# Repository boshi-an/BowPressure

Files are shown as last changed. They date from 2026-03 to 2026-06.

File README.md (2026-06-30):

# Force-sensing Violin/Cello Bow Setup

This repo provides a systemetical way to capture human violin playing data.

## Preparation (From Scratch)

- Arduino Uno (R3 or R4)
- High Precision AD HAT [Weshare](https://www.waveshare.com/wiki/High-Precision_AD_HAT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)
- BNO055 board [DFRobot](https://wiki.dfrobot.com/sen0374/)
- Bow attached with strain gauges

## Wirings (From Scratch)

Before powering the board, please check twice the connections to avoid burning the board!!!

Arduino UNO -> AD HAT:

- Arduino `D13 (SCK)` -> `SCLK`
- Arduino `D11 (MOSI)` -> `DIN`
- Arduino `D12 (MISO)` -> `DOUT`
- Arduino `D10` -> `CS`
- Arduino `D2` -> `DRDY`
- Arduino `D4` -> `RESET` / `REST`
- Arduino `5V` -> `VCC` (digital logic supply)
- Arduino `5V` -> `AVDD` (analog supply) via the screw terminal block

For the differential mode used in this project, the following shoud NOT be connected:
- `GND` -> `AVSS`

AD Hat to Bow Bridge

- AD Hat `IN0-VCC` -> Bow `E+`
- AD Hat `IN0-GND` -> Bow `E-`
- AD Hat `IN0-AIN` -> Bow `S+`
- AD Hat `IN1-AIN` -> Bow `S-`

Arduino UNO -> BNO055

- Arduino `SDA` -> `SDA`
- Arduino `SCL` -> `SCL`
- Arduino `5V` -> `VCC`
- Arduino `GND` -> `GND`

Arduino UNO -> LTC signal

- Arduino `D3` -> Normalized input

The Normalized input is the raw input biased to fit the Arduino logic.

## Wirings (Already integrated)

- Label ADC:L and ADC:R to ADC. Read the section above to understand the connector orientation.
- Label AVDD to the AVDD screw terminal on the ADC board.
- Label ARD:1, ARD:2 and ARD:3 to Arduino. Read the section above to understand the connector orientation.

## Compiling

Before powering the board, please check twice the connections to avoid burning the board!!!

1. Connect the Arduino to computer
2. Connect the Arduino to 9-12V power input
3. List boards connected 

```bash
arduino-cli board list
```

4. Compile controller program (pick the right FQBN for your board, as displayed by the previous command)

```bash
arduino-cli compile --fqbn <FQBN> realtime-arduino/ads1263_bno055_reader
```

5. Upload program to controller

```bash
arduino-cli upload -p <PORT> --fqbn <FQBN> realtime-arduino/ads1263_bno055_reader
```

6. Monitor output

For graphical monitoring:

```bash
python realtime-arduino/graphics_logger.py
```

This script supports loading fitted acceleration compensation model and display the compensated readings in realtime.

For legacy command-line based monitoring and recording:

```bash
python realtime-arduino/stream_logger.py --port <PORT> --baud 230400 --output recordings/ads1263.csv
```

## Calibration

Calibration requires the Arduino already running the controller above.

```bash
python realtime-arduino/calibration.py calibrations/bow.json
```

The calibration data will be appended to the old file if exists.

## Calibration Fitting

```bash
python analysis_calibration_data.py calibrations/bow.json
```

This will generate the quadratic terms for the calibration in `calibrations/bow_params.json`

## Acceleration Compensation

Acceleration Compensation requires a recorded csv file generated by `realtime-arduino/stream_logger.py`

```bash
python acceleration_compensation/fit.py recordings/ads1263.csv --model <mlp/linear> --epochs 1000 --n-past 10 --n-future 0
```

The program will save the fitted model to the same directory of the csv file.

## LTC Input

LTC input requires an additional LM2903P chip for pulling the input voltage to Arduino logic. The [ltc_reader](realtime-arduino/ads1263_bno055_reader/ads1263_bno055_reader.ino) includes a sample code for displaying received LTC timestamps, the [main_program](realtime-arduino/ads1263_bno055_reader/ads1263_bno055_reader.ino) supports LTC input, when LTC input is available, timestamps will automatically be included in the saved trace files. Files need modifications on `LTC_FPS` to adapt to your specific LTC setting.

The schematics for LTC reading circuit are included [in this file](figures/Circuit/SCH_Schematic2_2026-04-30.pdf). The circuit is capable of detecting very small signals (less than 100mVpp) to large signals (up to 3.3Vpp). The signal is not required to be centered at 0V.

You may generate LTC signals by playing LTC audio generated [on this website](https://elteesee.pehrhovey.net) and wire it to the LTC input circuit through the 3.5mm Audio Jack.

The compatibility with [Cubase LTC](https://www.steinberg.help/r/cubase-pro/15.0/en/cubase_nuendo/topics/synchronization/synchronization_timecode_standards_c.html) still requires confirmation, but in theory it should work.

# Data Collection with Mocap

The sensorized bow can be used together with april tag clamps on the bow and the violin to do violin playing motion data captuer.

The 3D model files for the clamps are at [OnShape](https://cad.onshape.com/documents/7d9b660bd9e12f1896edefd1/w/8b9ee4686a368937af61d3e0/e/939a0500c785a22a848d996b). These models are also licensed under [CC BY-NC-SA 4.0](https://creativecommons.org/licenses/by-nc-sa/4.0/).

The apriltags models are at [here](figures/Apriltags).

The Mocap data processing pipeline is not yet opensourced.

## Data Compression

To capture human motion and instrument pose at the same time, we used visible light motion capturing system (different from usual IR based mocap system).

The raw data of motion capture is trmendously big. At [ETH AIT volumetric capturing lab](https://volumetric-capture.ait.ethz.ch/), the produced data is aronud 200GB per second.

For more efficient data transmission, storage and processing, we developed ways to compress the raw data into more compact forms. We have provided a script for compressing `.dng` raw images of motion capture frames into mp4 videos or jpg images. With mp4 compression, we can have a compression rate of over `2000x`.

This script works with any generic directory structure. It replaces dng files with mp4 videos or jpg files in the destination path, and copies any other files as-is.

This command will compress the dataset into mp4 files:

```bash
python compress_dataset.py --src SRC_PATH --dst DST_PATH --skip-preview --crf 30 --workers 4 --resume
```

The `--crf` option controls the quality, the lower the better quality and larger size. 30 keeps the details of the images and still have a very small file volume. Notice that MP4 encoding uses motion compensation, which uses predicted pixel block movement to encode motion thus harmful for accuracy of motion capture. So if you want unbiased data, we recommend you use the following jpg style compression, which preserves the motion but loses pixel color fidelity.

This command will compress the dataset into jpg files:

```bash
python compress_dataset.py --src /mnt/ait/work/srl_lab/cameras/SRL_lab/violin_test_Jun16 --dst /mnt/violin/Violin_test_Jun16 --skip-preview --format jpg --jpeg-quality 85 --workers 4
```

Teh `--jpeg-quality` controls the quality, the higher the better quality. 85 is a very high quality, usually we can lower this to 65 or even smaller numbers.

# License

This project is licensed under [CC BY-NC-SA 4.0](https://creativecommons.org/licenses/by-nc-sa/4.0/).  
Free for research and personal use. Commercial use is prohibited.  
Derivatives must use the same license.

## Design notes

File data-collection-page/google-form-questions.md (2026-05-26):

# Google Form — Violin Playing Study

**Form title:** Violin Playing Study — Sign-up & Background Form
**Subtitle:** Force-sensitive Violin Playing Dataset · ETH Zurich Soft Robotics Lab

**Form description:**
> Thank you for your interest in participating in our violin playing research study at ETH Zurich. This form takes about 5 minutes. We will use your answers to confirm eligibility and schedule your session.
>
> Contact: Boshi An · boshan@ethz.ch · Soft Robotics Lab, ETH Zurich

---

## Section 1 — Contact & Scheduling

1. **Full name** *(short answer, required)*
2. **Email address** *(short answer, required)*
3. **Phone number** *(short answer, optional)*
4. **Preferred session dates / availability** *(paragraph, e.g. "weekday afternoons after May 15")*

---

## Section 2 — Eligibility Screening

5. **Are you 18 years of age or older?** *(required)*
   - Yes
   - No → *route to not-eligible closing screen*

6. **Do you currently have any musculoskeletal pain or injury that would make violin playing uncomfortable or unsafe?** *(required)*
   - No
   - Yes — please describe below

   6a. If yes, please describe briefly *(short answer, shown only if Yes)*

7. **Do you have photosensitive epilepsy or a related condition?** *(required)*
   - No
   - Yes → *route to not-eligible closing screen*

> ⚠️ The study uses bright infrared strobe lights for motion capture. Participants with photosensitive epilepsy or a related condition are not eligible.

---

## Section 3 — Musical Background

8. **How many years have you been playing violin?** *(required)*
   - 5–9 years
   - 10–14 years
   - 15–19 years
   - 20+ years

9. **How would you describe your current playing level?** *(required)*
   - Advanced (conservatory / university level)
   - Professional / semi-professional

10. **Bowing hand** *(required)*
    - Right hand
    - Left hand

11. **What is your primary musical context?** *(checkboxes, select all that apply)*
    - Classical / orchestral
    - Chamber music
    - Folk / traditional
    - Jazz / improvised
    - Other

12. **Do you have any upcoming performance or competition in the next 4 weeks that might be affected by participating?**
    - No
    - Yes

---

## Section 4 — Piece Preparation

> The lab provides a violin and bow — you do not need to bring your own instrument.

13. **What piece(s) are you planning to prepare for the session?** *(paragraph, required)*
    - Title, composer, approximate duration (e.g. "Bach Partita No. 2 in D minor, ~12 min")

14. **Estimated total performance duration** *(required)*
    - 3–5 min
    - 5–10 min
    - 10–15 min

---

## Section 5 — Data Consent Preferences

> A full printed consent form with your signature will be completed at the start of your session. These questions capture your initial preferences — you can change them on the day.

15. **I agree that my data (motion, force, audio) may be published in anonymised form in scientific outputs.** *(required)*
    - Yes, I agree
    - I have questions — please contact me

16. **I would like my data published or shared in non-anonymised form (linked to my identity).**
    - Yes
    - No, keep my data anonymised only

17. **I would like my data shared with academic collaborators outside ETH Zurich in non-anonymised form.**

    > Sharing with collaborators means your data (motion, force, audio) may be accessed by a small number of researchers in selected partner groups (e.g. Tsinghua University) for the purposes of this study. This is closed-circulation academic sharing — it does not mean your data will be published publicly or non-anonymously. Sharing with collaborators allows for broader scientific analysis and benefits the research community. You can still choose to have all public outputs anonymised regardless of your answer here.

    - Yes, I agree to share my data with selected academic collaborators in non-anonymised form
    - No, limit access to the ETH Zurich research team only

18. **I would like to be notified about the study results.**
    - Yes
    - No

---

## Section 6 — Anything Else?

19. **Any questions or comments for the researcher?** *(paragraph, optional)*

---

## Setup Notes

- **Routing:** use "Go to section based on answer" on Q5 (No) and Q7 (Yes) to send ineligible respondents to a closing screen.
- **Confirmation message:** *"Thank you! Boshi will contact you within a few days to schedule your session."*
- **Response notifications:** enable email alerts to boshan@ethz.ch on each submission.
- The printed consent form with physical signatures must still be completed in person — this form does not replace it for ETH ethics compliance.

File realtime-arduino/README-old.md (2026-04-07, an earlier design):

## Arduino ADS1263 Examples

Arduino sketches for the Waveshare High-Precision AD HAT (ADS1263), tested with **Arduino UNO** and **Arduino Mega 2560**.

### Sketches

- `arduino_self_check/arduino_self_check.ino`
  - Basic board health check (serial output, LED heartbeat, optional A0 read).
- `ads1263_reader/ads1263_reader.ino`
  - ADS1263 differential capture on `IN0-IN1`
  - DRDY falling-edge interrupt sampling
  - Continuous streaming output lines: `DATA,timestamp_us,raw,mV`
  - Periodic stream stats lines: `STATS,fps=...,count=...,dropped_edges=...`
- `bno055_reader/bno055_reader.ino`
  - BNO055 IMU over I2C (`SDA`/`SCL`), **no third-party IMU library** (raw register I²C)
  - **ACCGYRO** mode only; configurable accel G-range, gyro °/s range, and both sensors’ bandwidth (see `bno055_reader/BNO055_ACC_GYRO.md`)
  - Outputs CSV: `t_ms,acc_x,acc_y,acc_z,gyr_x,gyr_y,gyr_z` (units: mg, dps)
- `ltc_reader/ltc_reader.ino`
  - Reads LTC (Linear Timecode) on `D2` (UNO `INT0`, edge interrupt)
  - Prints current decoded SMPTE timecode lines: `HH:MM:SS:FF`
- `stream_logger.py`
  - Laptop-side logger that waits on serial stream and records CSV

### Wiring (UNO -> AD HAT)

- `D13 (SCK)` -> `SCLK`
- `D11 (MOSI)` -> `DIN`
- `D12 (MISO)` -> `DOUT`
- `D10` -> `CS`
- `D2` -> `DRDY`
- `D4` -> `RESET` / `REST`
- `5V` -> `AVDD` (analog supply)
- `5V` -> `VCC` (digital logic supply)
- `GND` -> `AVSS` (or `COM` if AVSS-COM is already tied)

### Wiring (Mega 2560 -> AD HAT)

- `D52 (SCK)` -> `SCLK`
- `D51 (MOSI)` -> `DIN`
- `D50 (MISO)` -> `DOUT`
- `D53` -> `CS`
- `D2` -> `DRDY`
- `D4` -> `RESET` / `REST`
- `5V` -> `AVDD` (analog supply)
- `3.3V` -> `VCC` (digital logic supply)
- `GND` -> `AVSS` (or `COM` if AVSS-COM is already tied)

### Important Electrical Note

The AD HAT is Raspberry-Pi-oriented (3.3V logic). UNO/Mega pins are 5V.
Use level shifting on outputs (`SCLK`, `DIN`, `CS`, `RESET`) for safe operation.

### Build and Upload (arduino-cli)

From project root:

```bash
cd /home/boshi/Documents/BowPressure
```

List boards/ports:

```bash
arduino-cli board list
```

Compile ADS1263 reader (pick the right FQBN for your board):

```bash
arduino-cli compile --fqbn <FQBN> realtime-arduino/ads1263_reader
```

Compile self-check (pick the right FQBN for your board):

```bash
arduino-cli compile --fqbn <FQBN> realtime-arduino/arduino_self_check
```

Compile LTC reader:

```bash
arduino-cli compile --fqbn <FQBN> realtime-arduino/ltc_reader
```

Upload ADS1263 reader:

```bash
arduino-cli upload -p /dev/ttyACM1 --fqbn <FQBN> realtime-arduino/ads1263_reader
```

Important: the `--fqbn` must match the exact board you are using.
For example:
- Arduino UNO R4 WiFi: `arduino:renesas_uno:unor4wifi`
- Arduino UNO (classic AVR): `arduino:avr:uno`
- Arduino Mega 2560 (AVR): `arduino:avr:mega`
- Do `arduino-cli board list` to see your fqbn.

Replace `/dev/ttyACM1` with the port shown by `arduino-cli board list` for your setup.

### Laptop Logger

Install dependency:

```bash
python -m pip install pyserial
```

Run logger (matches sketch baud rate `230400`):

```bash
python realtime-arduino/stream_logger.py --port /dev/ttyACM1 --baud 230400 --output ads1263_stream.csv
```

Optional timed run (example: 20 seconds):

```bash
python realtime-arduino/stream_logger.py --port /dev/ttyACM1 --baud 230400 --output ads1263_stream.csv --duration 20
```

### Expected ADS1263 Reader Output

- Register configuration verification lines (`REG_MODE*`, `REG_REFMUX`)
- Stream start message
- Repeating sample lines:
  - `DATA,timestamp_us,raw,mV`
- Periodic status lines:
  - `STATS,fps=...,count=...,dropped_edges=...`

### BNO055 (IMU) Wiring + Notes

- Connect IMU `SDA` -> Arduino `SDA` (UNO R4: labeled SDA, often D14)
- Connect IMU `SCL` -> Arduino `SCL` (UNO R4: labeled SCL, often D15)
- Connect IMU `3V3` (or `VIN` per breakout) and `GND` per your board datasheet
- Default I2C address is usually `0x28` (`BNO055_ADDRESS_A`); some boards use `0x29`

**UNO R4 WiFi** — compile/upload example (adapt port from `arduino-cli board list`):

```bash
arduino-cli compile --fqbn arduino:renesas_uno:unor4wifi realtime-arduino/bno055_reader
arduino-cli upload -p /dev/ttyACM0 --fqbn arduino:renesas_uno:unor4wifi realtime-arduino/bno055_reader
arduino-cli monitor -p /dev/ttyACM0 -c baudrate=115200
```

No extra libraries are required for `bno055_reader` (uses `Wire` only).

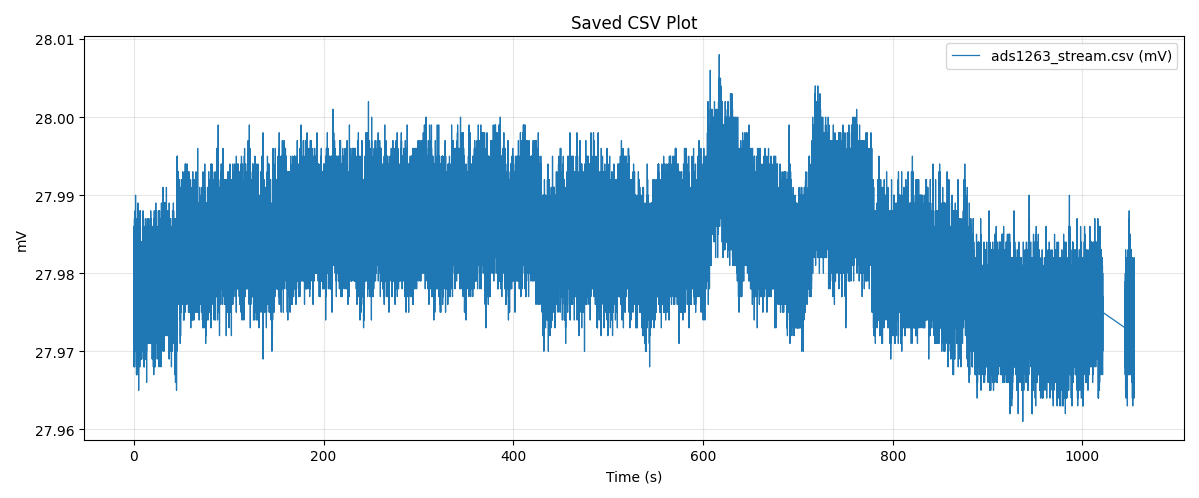
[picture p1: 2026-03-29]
figures/drift-CA80-full-5h.png

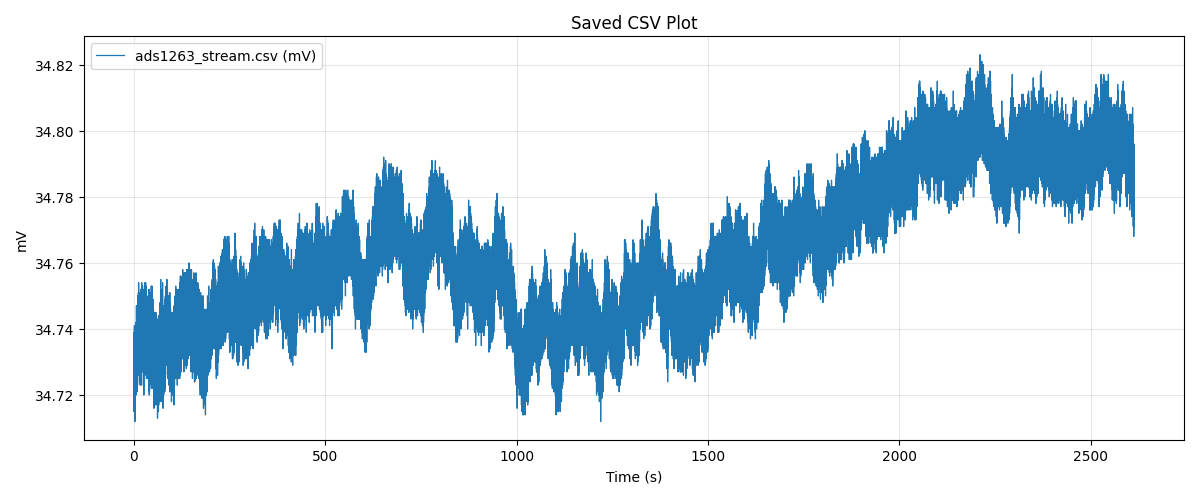
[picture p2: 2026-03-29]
figures/drift-406-half-10d.png

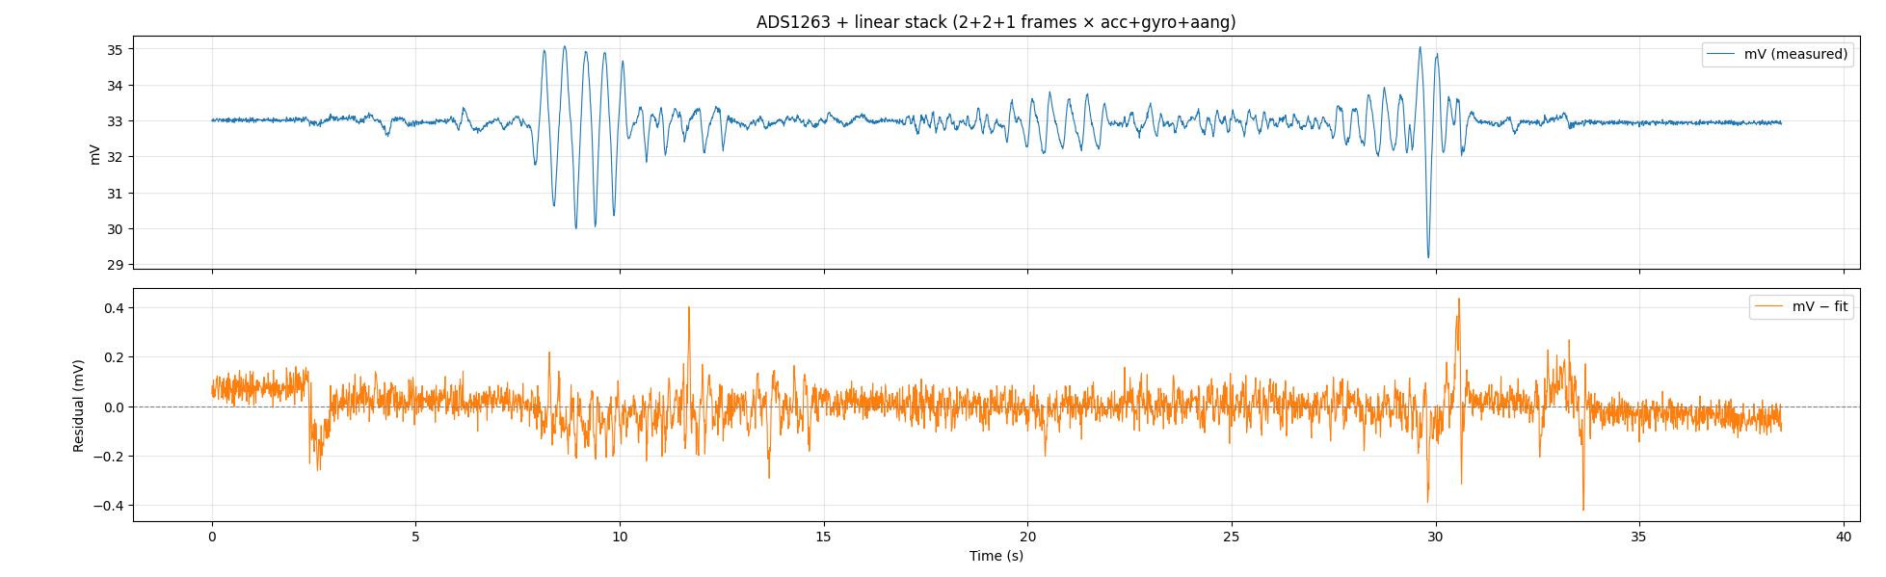
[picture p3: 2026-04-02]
figures/compensation.png

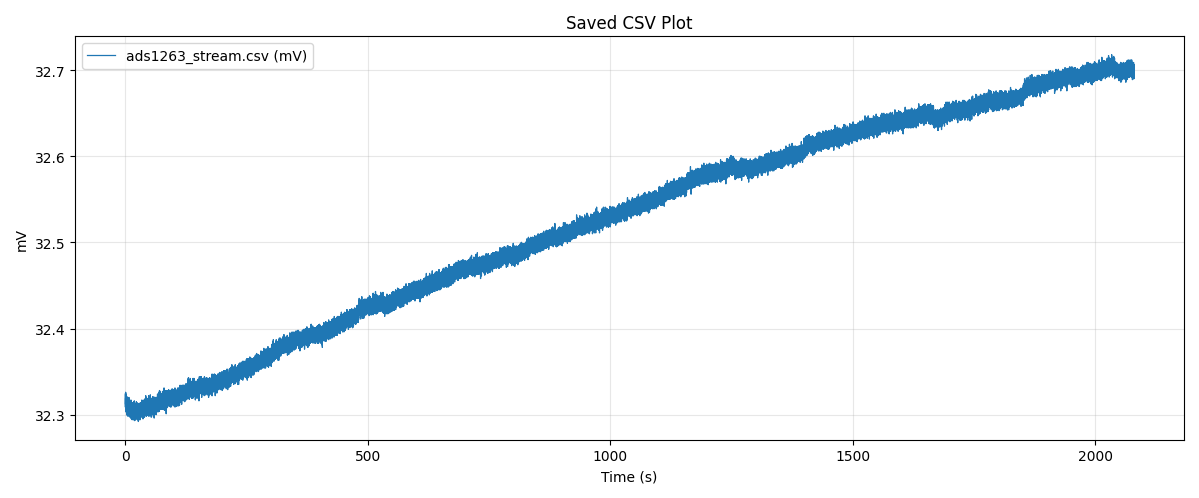
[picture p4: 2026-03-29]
figures/drift-CA80-full-1h.png

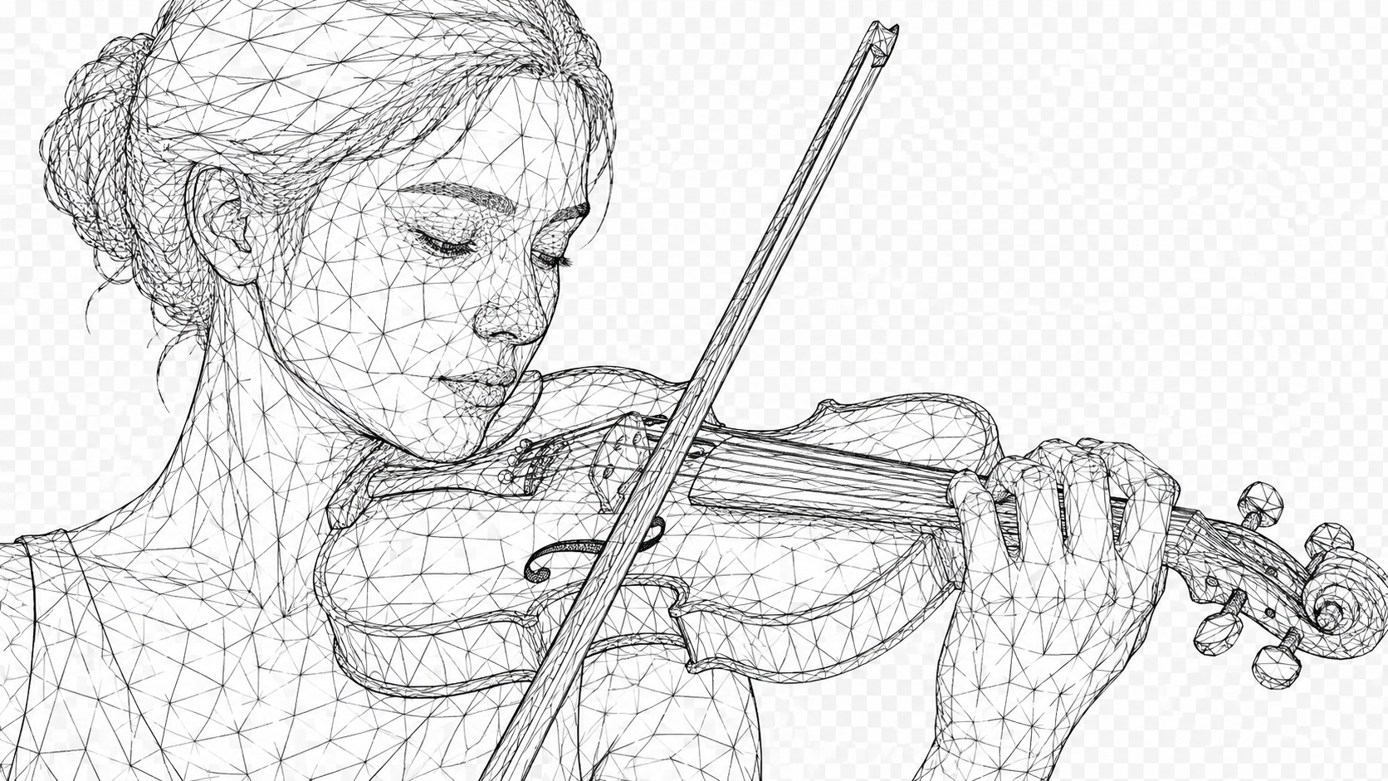
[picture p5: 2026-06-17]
data-collection-page/wire-frame-violinist.png

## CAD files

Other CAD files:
figures/Apriltags/Apriltag-0-7.gcode.3mf

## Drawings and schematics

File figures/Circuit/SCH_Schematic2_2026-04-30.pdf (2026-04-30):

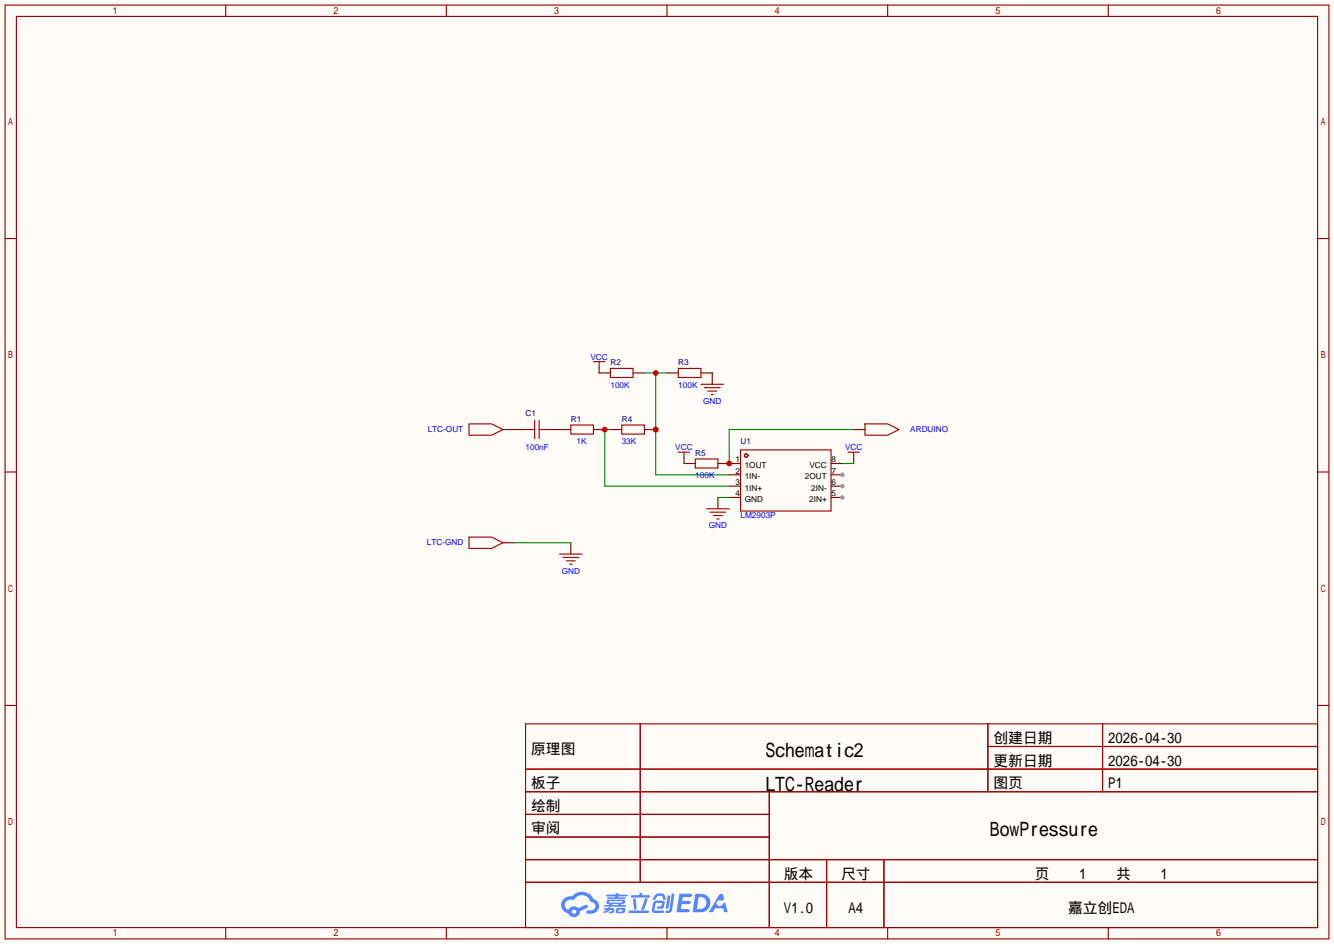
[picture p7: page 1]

原理图 | Schematic2 | 创建日期 | 2026-04-30

更新日期 | 2026-04-30

板子 | LTC-Reader | 图页 | P1
绘制 | | BowPressure
审阅

V1.0 | A4 | 嘉立创EDA

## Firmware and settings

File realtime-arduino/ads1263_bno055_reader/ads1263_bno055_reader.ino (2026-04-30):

#include <SPI.h>
#include <Wire.h>
#include "DFRobot_BNO055.h"

// Must appear before any function definitions: Arduino injects prototypes after includes,
// so these types must be visible before generated `adsSetInputMode` / `adsConfigAdc1` protos.
enum class InputMode : uint8_t {
  SingleEnded = 0,  // AINx vs AINCOM
  Differential = 1  // AINp vs AINn
};

enum class FilterMode : uint8_t {
  FIR = 0x84,
  Sinc1 = 0x04,
  Sinc2 = 0x24,
  Sinc3 = 0x44,
  Sinc4 = 0x64
};

typedef DFRobot_BNO055_IIC BNO;
BNO* g_bno = nullptr;

static const uint8_t kBnoI2cAddr = 0x28;

// --- BNO055 configuration (CONFIG mode; DFRobot_BNO055 / Bosch BNO055) ---
static const BNO::eAccRange_t kAccRange = BNO::eAccRange_4G;
static const BNO::eGyrRange_t kGyrRange = BNO::eGyrRange_500;
static const BNO::eAccBandWidth_t kAccBandWidth = BNO::eAccBandWidth_125;
static const BNO::eGyrBandWidth_t kGyrBandWidth = BNO::eGyrBandWidth_116;

static void configureBno055(BNO* bno) {
  bno->setOprMode(BNO::eOprModeConfig);
  bno->setAccRange(kAccRange);
  bno->setGyrRange(kGyrRange);
  bno->setPowerMode(BNO::ePowerModeNormal);
  bno->setAccPowerMode(BNO::eAccPowerModeNormal);
  bno->setGyrPowerMode(BNO::eGyrPowerModeNormal);
  bno->setAccBandWidth(kAccBandWidth);
  bno->setGyrBandWidth(kGyrBandWidth);
  bno->setOprMode(BNO::eOprModeAccGyro);
  delay(2000);
}

void printLastOperateStatus(BNO::eStatus_t eStatus) {
  switch (eStatus) {
  case BNO::eStatusOK:
    Serial.println(F("everything ok"));
    break;
  case BNO::eStatusErr:
    Serial.println(F("unknow error"));
    break;
  case BNO::eStatusErrDeviceNotDetect:
    Serial.println(F("device not detected"));
    break;
  case BNO::eStatusErrDeviceReadyTimeOut:
    Serial.println(F("device ready time out"));
    break;
  case BNO::eStatusErrDeviceStatus:
    Serial.println(F("device internal status error"));
    break;
  default:
    Serial.println(F("unknow status"));
    break;
  }
}

// ===== Pin mapping (keep UNO wiring on all boards) =====
constexpr uint8_t PIN_CS = 10;   // ADS1263 CS (same as UNO wiring)
constexpr uint8_t PIN_DRDY = 2;  // DRDY to D2 (same as UNO wiring)
constexpr uint8_t PIN_RST = 4;   // ADS1263 RESET (same as UNO wiring)
constexpr uint8_t PIN_LTC = 3;   // LTC signal input (external interrupt pin on UNO)
#if defined(ARDUINO_AVR_MEGA2560)
constexpr uint8_t PIN_HW_SS = 53;  // Mega SPI master pin (internal requirement)
#else
constexpr uint8_t PIN_HW_SS = 10;  // UNO/R4 SPI master pin
#endif
constexpr float ADC_REF_MV = 5000.0f;  // Set to measured AVDD in mV for accuracy
constexpr uint8_t DIFF_AIN_P = 0;      // Differential + input: IN0
constexpr uint8_t DIFF_AIN_N = 1;      // Differential - input: IN1
constexpr uint32_t STREAM_BAUD = 230400;
constexpr uint32_t STREAM_STATS_INTERVAL_MS = 1000;

volatile bool g_samplePending = false;
volatile uint32_t g_pendingTimestampUs = 0;
volatile uint32_t g_droppedEdges = 0;

uint32_t g_streamCount = 0;
uint32_t g_lastStatsMs = 0;
uint32_t g_lastStatsCount = 0;

// ===== LTC decoder state =====
// Decodes LTC BMC edges on PIN_LTC and stores latest HH:MM:SS:FF.
#define LTC_FPS 30
#define HALF_BIT_US (1000000 / (LTC_FPS * 80 * 2))
#define NOISE_THRESHOLD (HALF_BIT_US / 10)
#define SHORT_MIN (HALF_BIT_US / 3)
#define SHORT_MAX (HALF_BIT_US * 3 / 2)
#define LONG_MAX (HALF_BIT_US * 3)

volatile uint32_t g_ltcLastEdge = 0;
volatile uint8_t g_ltcHalfCount = 0;
volatile uint8_t g_ltcBitCount = 0;
volatile uint8_t g_ltcBitBuf[10] = {0};
volatile bool g_ltcFrameReady = false;
volatile uint8_t g_ltcFrame[10] = {0};

char g_ltcText[12] = "";
bool g_ltcValid = false;

// ===== ADS1263 command/register map (subset) =====
constexpr uint8_t CMD_RESET = 0x06;
constexpr uint8_t CMD_START1 = 0x08;
constexpr uint8_t CMD_STOP1 = 0x0A;
constexpr uint8_t CMD_RDATA1 = 0x12;

constexpr uint8_t REG_MODE0 = 0x03;
constexpr uint8_t REG_MODE1 = 0x04;   // digital filter settings
constexpr uint8_t REG_MODE2 = 0x05;   // data rate in low nibble
constexpr uint8_t REG_INPMUX = 0x06;  // [7:4]=AINP [3:0]=AINN
constexpr uint8_t REG_REFMUX = 0x0F;  // use AVDD/AVSS by default

constexpr uint8_t AINCOM = 0x0A;

// DR code table from ADS1263 MODE2.DR[3:0] setting.
// This helper focuses on common rates and picks the nearest one.
uint8_t rateToDrCode(uint16_t sps) {
  struct Pair {
    uint16_t sps;
    uint8_t dr;
  };
  static const Pair table[] = {
      {2, 0x00},   {5, 0x01},    {10, 0x02},   {16, 0x03},   {20, 0x04},
      {50, 0x05},  {60, 0x06},   {100, 0x07},  {400, 0x08},  {1200, 0x09},
      {2400, 0x0A}, {4800, 0x0B}, {7200, 0x0C}, {14400, 0x0D}, {19200, 0x0E},
      {38400, 0x0F}};

  uint8_t best = table[0].dr;
  uint16_t bestDiff = 65535;
  for (const auto &item : table) {
    uint16_t diff = (item.sps > sps) ? (item.sps - sps) : (sps - item.sps);
    if (diff < bestDiff) {
      bestDiff = diff;
      best = item.dr;
    }
  }
  return best;
}

void csLow() { digitalWrite(PIN_CS, LOW); }
void csHigh() { digitalWrite(PIN_CS, HIGH); }

void adsWriteCommand(uint8_t cmd) {
  csLow();
  SPI.transfer(cmd);
  csHigh();
}

void adsWriteRegister(uint8_t reg, uint8_t value) {
  // WREG format: 010r rrrr, then count-1, then data bytes.
  csLow();
  SPI.transfer(0x40 | (reg & 0x1F));
  SPI.transfer(0x00);  // write 1 register
  SPI.transfer(value);
  csHigh();
}

uint8_t adsReadRegister(uint8_t reg) {
  // RREG format: 001r rrrr, then count-1, then read data bytes.
  csLow();
  SPI.transfer(0x20 | (reg & 0x1F));
  SPI.transfer(0x00);  // read 1 register
  uint8_t v = SPI.transfer(0x00);
  csHigh();
  return v;
}

void adsHardwareReset() {
  digitalWrite(PIN_RST, LOW);
  delay(2);
  digitalWrite(PIN_RST, HIGH);
  delay(10);
}

void adsInit() {
  pinMode(PIN_HW_SS, OUTPUT);
  digitalWrite(PIN_HW_SS, HIGH);
  pinMode(PIN_CS, OUTPUT);
  pinMode(PIN_RST, OUTPUT);
  pinMode(PIN_DRDY, INPUT_PULLUP);
  csHigh();
  digitalWrite(PIN_RST, HIGH);

  SPI.begin();
  // ADS1263 uses SPI mode 1, MSB first, <=8MHz. Use 4MHz for stability.
  SPI.beginTransaction(SPISettings(4000000, MSBFIRST, SPI_MODE1));

  adsHardwareReset();
  adsWriteCommand(CMD_RESET);
  delay(5);
}

// 1) Activate input mode and selected channel(s)
void adsSetInputMode(InputMode mode, uint8_t ainP, uint8_t ainN) {
  if (mode == InputMode::SingleEnded) {
    // Single-ended: channel vs AINCOM.
    if (ainP >= 10 || ainN >= 10) {
      Serial.println("Error: Single-ended input must be between 0 and 9");
      return;
    }
    adsWriteRegister(REG_INPMUX, ((ainP & 0x0F) << 4) | (AINCOM & 0x0F));
  } else {
    if (ainP >= 10 || ainN >= 10) {
      Serial.println("Error: Differential input must be between 0 and 9");
      return;
    }
    if (ainP == ainN) {
      Serial.println("Error: Differential input must be different");
      return;
    }
    if (ainP+1 != ainN or ainP%2 != 0) {
      Serial.println("Error: Differential input must be consecutive and paired");
      return;
    }
    // Differential: AINp vs AINn.
    adsWriteRegister(REG_INPMUX, ((ainP & 0x0F) << 4) | (ainN & 0x0F));
  }
}

bool adsWriteRegVerified(uint8_t reg, uint8_t value, const char *name) {
  adsWriteRegister(reg, value);
  delay(1);
  uint8_t got = adsReadRegister(reg);
  bool ok = (got == value);
  Serial.print(name);
  Serial.println(ok ? " success" : " unsuccess");
  if (!ok) {
    Serial.print("  expected=0x");
    Serial.print(value, HEX);
    Serial.print(" got=0x");
    Serial.println(got, HEX);
  }
  return ok;
}

// Mirrors Waveshare ADS1263_ConfigADC1 flow:
// MODE2 -> REFMUX -> MODE0 -> MODE1, each with readback verification.
void adsConfigAdc1(uint8_t gain, uint8_t drate, uint8_t delayReg, FilterMode filterMode) {
  uint8_t mode2 = 0x80;  // PGA bypassed
  mode2 |= ((gain & 0x07) << 4) | (drate & 0x0F);
  adsWriteRegVerified(REG_MODE2, mode2, "REG_MODE2");

  uint8_t refmux = 0x24;  // AVDD/AVSS as reference (matches Waveshare/Pi example)
  adsWriteRegVerified(REG_REFMUX, refmux, "REG_REFMUX");

  uint8_t mode0 = delayReg;
  adsWriteRegVerified(REG_MODE0, mode0, "REG_MODE0");

  if (FilterMode::FIR == filterMode && drate > 20) {
    Serial.println("Error: FIR filter is not supported for data rates greater than 20 SPS");
    return;
  }
  uint8_t mode1 = static_cast<uint8_t>(filterMode);
  adsWriteRegVerified(REG_MODE1, mode1, "REG_MODE1");
}

int32_t adsReadAdc1RawInline() {
  csLow();
  SPI.transfer(CMD_RDATA1);
  (void)SPI.transfer(0x00);  // status
  uint8_t b3 = SPI.transfer(0x00);
  uint8_t b2 = SPI.transfer(0x00);
  uint8_t b1 = SPI.transfer(0x00);
  uint8_t b0 = SPI.transfer(0x00);
  (void)SPI.transfer(0x00);  // checksum
  csHigh();
  return (int32_t)(((uint32_t)b3 << 24) | ((uint32_t)b2 << 16) |
                   ((uint32_t)b1 << 8) | (uint32_t)b0);
}

void ltcPushBit(uint8_t bit) {
  for (int i = 0; i < 9; i++) {
    g_ltcBitBuf[i] = (g_ltcBitBuf[i] >> 1) | ((g_ltcBitBuf[i + 1] & 0x01) << 7);
  }
  g_ltcBitBuf[9] = (g_ltcBitBuf[9] >> 1) | (bit << 7);

  g_ltcBitCount++;
  if (g_ltcBitCount > 80) g_ltcBitCount = 80;

  uint16_t sync = ((uint16_t)g_ltcBitBuf[9] << 8) | g_ltcBitBuf[8];
  if ((sync == 0xBFFC || sync == 0x3FFD) && g_ltcBitCount == 80) {
    memcpy((void *)g_ltcFrame, (void *)g_ltcBitBuf, 10);
    g_ltcFrameReady = true;
    g_ltcBitCount = 0;
    memset((void *)g_ltcBitBuf, 0, 10);
  }
}

void onLtcEdge() {
  uint32_t now = micros();
  uint32_t duration = now - g_ltcLastEdge;
  g_ltcLastEdge = now;

  if (duration < NOISE_THRESHOLD) {
    return;
  }

  if (duration < SHORT_MIN || duration > LONG_MAX) {
    g_ltcHalfCount = 0;
    return;
  }

  if (duration <= SHORT_MAX) {
    g_ltcHalfCount++;
    if (g_ltcHalfCount == 2) {
      g_ltcHalfCount = 0;
      ltcPushBit(1);
    }
  } else {
    g_ltcHalfCount = 0;
    ltcPushBit(0);
  }
}

void pollLtc() {
  if (!g_ltcFrameReady) return;

  uint8_t f[10];
  noInterrupts();
  memcpy(f, (void *)g_ltcFrame, 10);
  g_ltcFrameReady = false;
  interrupts();

  uint8_t ff = (f[0] & 0x0F) + ((f[1] & 0x03) * 10);
  uint8_t ss = (f[2] & 0x0F) + ((f[3] & 0x07) * 10);
  uint8_t mm = (f[4] & 0x0F) + ((f[5] & 0x07) * 10);
  uint8_t hh = (f[6] & 0x0F) + ((f[7] & 0x03) * 10);

  if (hh > 23 || mm > 59 || ss > 59 || ff > 29) {
    return;
  }

  snprintf(g_ltcText, sizeof(g_ltcText), "%02u:%02u:%02u:%02u", hh, mm, ss, ff);
  g_ltcValid = true;
}

void onDrdyFalling() {
  uint32_t t = micros();
  if (g_samplePending) {
    ++g_droppedEdges;
  } else {
    g_pendingTimestampUs = t;
    g_samplePending = true;
  }
}

float rawToMilliVolts(int32_t raw) {
  // ADS1263 bipolar code: -0x80000000 .. +0x7FFFFFFF maps to -VREF .. +VREF.
  constexpr float ADC_FULL_SCALE_POS = 2147483647.0f;  // 0x7FFFFFFF
  return (static_cast<float>(raw) / ADC_FULL_SCALE_POS) * ADC_REF_MV;
}

float sqrtNewton(float x) {
  if (x <= 0.0f) return 0.0f;
  float r = x;
  for (uint8_t i = 0; i < 12; ++i) {
    r = 0.5f * (r + x / r);
  }
  return r;
}

void setup() {
  Serial.begin(STREAM_BAUD);
  while (!Serial) { delay(10); }

  Wire.begin();
  Wire.setClock(50000);

  g_bno = new BNO(&Wire, kBnoI2cAddr);
  g_bno->reset();

  while (g_bno->begin() != BNO::eStatusOK) {
    Serial.println(F("bno begin failed, retrying..."));
    printLastOperateStatus(g_bno->lastOperateStatus);
    delay(2000);
  }
  Serial.println(F("bno begin success"));

  configureBno055(g_bno);
  Serial.println(
      F("configured: ACCGYRO, 4g / 500 dps, NORMAL power; IMU via getAxis (acc, gyr)"));
  Wire.setClock(50000);

  adsInit();

  // Differential mode on IN0-IN1, ~100 SPS (DRDY drives sample rate; IMU read once per ADC sample).
  adsSetInputMode(InputMode::Differential, DIFF_AIN_P, DIFF_AIN_N);
  adsConfigAdc1(
      0x00,               // gain=1
      rateToDrCode(100),  // drate target
      0x00,               // conversion delay register
      FilterMode::Sinc1   // filter mode
  );

  const int drdyInterrupt = digitalPinToInterrupt(PIN_DRDY);
  if (drdyInterrupt < 0) {
    Serial.println(F("Error: PIN_DRDY does not support external interrupt"));
    while (true) {
      delay(1000);
    }
  }
  attachInterrupt(drdyInterrupt, onDrdyFalling, FALLING);
  const int ltcInterrupt = digitalPinToInterrupt(PIN_LTC);
  if (ltcInterrupt >= 0) {
    pinMode(PIN_LTC, INPUT);
    g_ltcLastEdge = micros();
    attachInterrupt(ltcInterrupt, onLtcEdge, CHANGE);
    Serial.println(F("LTC decoder enabled on D3"));
  } else {
    Serial.println(F("LTC disabled: PIN_LTC has no external interrupt"));
  }
  adsWriteCommand(CMD_START1);
  delay(10);

  g_lastStatsMs = millis();

  Serial.println(F("ADS1263 + BNO055 fused stream (~100 Hz from ADC DRDY)"));
#if defined(ARDUINO_AVR_MEGA2560)
  Serial.println(F("Target board: Arduino Mega 2560"));
#else
  Serial.println(F("Target board: Arduino UNO-class"));
#endif
  Serial.print(F("ADC1 differential: IN"));
  Serial.print(DIFF_AIN_P);
  Serial.print(F(" - IN"));
  Serial.println(DIFF_AIN_N);
  Serial.print(F("Serial baud="));
  Serial.println(STREAM_BAUD);
  Serial.println(F("# DATA: timestamp_us,raw,mV,acc_x,acc_y,acc_z,gyr_x,gyr_y,gyr_z[,ltc]"));
  Serial.println(F("# LTC field format: HH:MM:SS:FF (when available)"));
}

void loop() {
  pollLtc();

  bool hasSample = false;
  uint32_t drdyUs = 0;
  noInterrupts();
  if (g_samplePending) {
    hasSample = true;
    drdyUs = g_pendingTimestampUs;
    g_samplePending = false;
  }
  interrupts();

  if (hasSample) {
    int32_t raw = adsReadAdc1RawInline();
    float mv = rawToMilliVolts(raw);

    if (g_bno == nullptr) return;

    // Timestamp as close as possible to IMU acquisition (time-sensitive path).
    // We use the midpoint of the two IMU reads as the exported sample time.
    const uint32_t imuReadStartUs = micros();
    BNO::sAxisAnalog_t sGyr = g_bno->getAxis(BNO::eAxisGyr);
    const uint32_t imuReadEndUs = micros();
    BNO::sAxisAnalog_t sAcc = g_bno->getAxis(BNO::eAxisAcc);
    const uint32_t tsUs = imuReadStartUs + ((imuReadEndUs - imuReadStartUs) / 2);
    (void)drdyUs;  // retained for possible future latency diagnostics

    ++g_streamCount;

    Serial.print(F("DATA,"));
    Serial.print(tsUs);      Serial.print(',');
    Serial.print(raw);       Serial.print(',');
    Serial.print(mv, 3);     Serial.print(',');
    Serial.print((int)round(sAcc.x)); Serial.print(',');
    Serial.print((int)round(sAcc.y)); Serial.print(',');
    Serial.print((int)round(sAcc.z)); Serial.print(',');
    Serial.print(sGyr.x, 2);  Serial.print(',');
    Serial.print(sGyr.y, 2);  Serial.print(',');
    Serial.print(sGyr.z, 2);
    if (g_ltcValid) {
      Serial.print(',');
      Serial.print(g_ltcText);
    }
    Serial.println();
  }

  uint32_t nowMs = millis();
  if (nowMs - g_lastStatsMs >= STREAM_STATS_INTERVAL_MS) {
    uint32_t dCount = g_streamCount - g_lastStatsCount;
    float fps = (1000.0f * static_cast<float>(dCount)) /
                static_cast<float>(nowMs - g_lastStatsMs);
    uint32_t dropped = 0;
    noInterrupts();
    dropped = g_droppedEdges;
    interrupts();

    Serial.print(F("STATS,fps="));
    Serial.print(fps, 2);
    Serial.print(F(",count="));
    Serial.print(g_streamCount);
    Serial.print(F(",dropped_edges="));
    Serial.println(dropped);

    g_lastStatsMs = nowMs;
    g_lastStatsCount = g_streamCount;
  }
}

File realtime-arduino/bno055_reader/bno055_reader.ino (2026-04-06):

/*!
 * read_data.ino
 *
 * Download this demo to test read data from bno055
 * Data will print on your serial monitor
 *
 * Product: http://www.dfrobot.com.cn/goods-1860.html
 * Copyright   [DFRobot](http://www.dfrobot.com), 2016
 * Copyright   GNU Lesser General Public License
 *
 * version  V1.0
 * date  07/03/2019
 */

#include "DFRobot_BNO055.h"
#include "Wire.h"

typedef DFRobot_BNO055_IIC
    BNO; // ******** use abbreviations instead of full names ********

BNO* g_bno = nullptr;

// --- IMU configuration (CONFIG mode writes; see DFRobot_BNO055 / Bosch BNO055 datasheet) ---
// Full-scale ranges (library: eAccRange_t / eGyrRange_t).
static const BNO::eAccRange_t kAccRange = BNO::eAccRange_4G;
static const BNO::eGyrRange_t kGyrRange = BNO::eGyrRange_500;
// Accelerometer / gyroscope bandwidth (library maps these to chip BW bits; higher = faster
// settling, more responsive "sampling" of motion — use lower values to reduce noise).
static const BNO::eAccBandWidth_t kAccBandWidth = BNO::eAccBandWidth_125;
static const BNO::eGyrBandWidth_t kGyrBandWidth = BNO::eGyrBandWidth_116;

// Apply ACC+GYRO only mode, ranges, bandwidth, and highest-performance power settings:
// system PWR_MODE NORMAL, ACC_PWR_MODE NORMAL, GYR_PWR_MODE NORMAL (not low-power / suspend).
static void configureBno055(BNO* bno) {
  bno->setOprMode(BNO::eOprModeConfig);
  bno->setAccRange(kAccRange);
  bno->setGyrRange(kGyrRange);
  bno->setPowerMode(BNO::ePowerModeNormal);
  bno->setAccPowerMode(BNO::eAccPowerModeNormal);
  bno->setGyrPowerMode(BNO::eGyrPowerModeNormal);
  bno->setAccBandWidth(kAccBandWidth);
  bno->setGyrBandWidth(kGyrBandWidth);
  bno->setOprMode(BNO::eOprModeAccGyro);
  delay(2000);
}

// show last sensor operate status
void printLastOperateStatus(BNO::eStatus_t eStatus) {
  switch (eStatus) {
  case BNO::eStatusOK:
    Serial.println("everything ok");
    break;
  case BNO::eStatusErr:
    Serial.println("unknow error");
    break;
  case BNO::eStatusErrDeviceNotDetect:
    Serial.println("device not detected");
    break;
  case BNO::eStatusErrDeviceReadyTimeOut:
    Serial.println("device ready time out");
    break;
  case BNO::eStatusErrDeviceStatus:
    Serial.println("device internal status error");
    break;
  default:
    Serial.println("unknow status");
    break;
  }
}

void setup() {
  Serial.begin(230400);
  Serial.println("bno055_reader setup");
  g_bno = new BNO(&Wire, 0x28);
  g_bno->reset();
  while (g_bno->begin() != BNO::eStatusOK) {
    Serial.println("bno begin faild");
    printLastOperateStatus(g_bno->lastOperateStatus);
    delay(2000);
  }
  Serial.println("bno begin success");

  configureBno055(g_bno);
  Serial.println(
      "configured: ACCGYRO, 4g / 500 dps, NORMAL power; serial: raw acc (mg), gyro (dps)");
}

#define printAxisData(sAxis)                                                   \
  Serial.print(" z: ");                                                        \
  Serial.print(sAxis.z)

void loop() {
  BNO::sAxisAnalog_t sAccAnalog, sGyrAnalog;
  sAccAnalog = g_bno->getAxis(BNO::eAxisAcc);
  sGyrAnalog = g_bno->getAxis(BNO::eAxisGyr);
  Serial.print("acc (mg)  ");
  printAxisData(sAccAnalog);
  // Serial.print("gyr (dps) ");
  // printAxisData(sGyrAnalog);
  Serial.println();

  delay(10);
}

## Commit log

2026-03-24 RunesKee version of calibration code
2026-03-24 Added Arduino based data collection code
2026-04-30 using new ltc circuit
2026-05-09 added 3d models and apriltags and updated license
    [Apriltag-0-7.gcode.3mf]
2026-06-17 added materials
2026-07-17 acceleration_compensation: add mV_raw fit target and residual percentiles
    fit.py now selects the compensation target via --target {mV_ema, mV_raw}.
    mV_raw pairs with raw IMU features (acc_*_mg, gyr_*_dps, aang_*_raw_dps2) so the
    compensated signal stays unsmoothed, while mV_ema keeps the EMA features. The
    saved payload records target/feature_set/feature_columns and raw models get a
    _raw filename tag so both sit side by side. Fitting also reports the
    median/p5/p95 of the y - y_pred residual (persisted in the payload metrics).
2026-11-04 updated tsinghua related materials
2026-11-04 docs: clarify main programming cables and assembled bow wiring
2026-11-08 Sample the IMU at 3.2 kHz and stream at 3 Mbaud
